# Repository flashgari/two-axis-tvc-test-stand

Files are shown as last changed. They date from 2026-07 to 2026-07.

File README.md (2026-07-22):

# Two-Axis Thrust Vector Control Test Stand

Hardware GNC portfolio project to design, build, and test a benchtop two-axis thrust-vector-control mechanism from scratch.

## Project Goal

Build a physical two-axis gimbal test stand that points a mock rocket engine/nozzle, measures actuator and attitude response, runs closed-loop control on embedded hardware, and produces real test data.

This project is intentionally hardware-first. The objective is to demonstrate the full engineering loop:

```text
requirements -> CAD -> fabrication -> electronics -> firmware -> calibration -> test data -> iteration
```

## Current Project Status

Prototype 1 is in the pre-hardware verification stage. The design package is no longer just a concept: requirements, actuator sizing, BOM, CAD baseline, split STL exports, firmware skeleton, serial logging, analysis scripts, and pre-hardware response predictions are already in the repo.

The next engineering question is:

```text
How closely does the real printed gimbal match the predicted pitch/yaw dynamic response?
```

That question is answered by comparing predicted and measured step-response metrics for each axis. A good first test is not judged by perfect motion. It is judged by whether the measured response exposes the dominant nonideality: actuator lag, servo deadband, gear backlash, printed-structure compliance, bearing friction, wire preload, center-of-mass bias, sensor filtering, or supply-voltage sag.

| Stage | Status | Evidence |
| --- | --- | --- |
| Requirements and safety scope | complete | [docs/week0_requirements.md](docs/week0_requirements.md), [docs/safety_plan.md](docs/safety_plan.md) |
| Hardware selection and purchase package | complete | [docs/final_purchase_package.md](docs/final_purchase_package.md) |
| CAD baseline and printable Rev A parts | complete | [cad/](cad/) |
| Firmware and telemetry skeleton | complete | [firmware/](firmware/) |
| Analysis and plotting pipeline | complete | [docs/test_and_analysis_workflow.md](docs/test_and_analysis_workflow.md) |
| Pre-hardware dynamic prediction | complete | [docs/pre_hardware_simulation.md](docs/pre_hardware_simulation.md) |
| Rev A design review | complete | [docs/rev_a_design_review_summary.md](docs/rev_a_design_review_summary.md) |
| Build readiness package | complete | [docs/build_readiness_checklist.md](docs/build_readiness_checklist.md) |
| Calibration and first-test worksheet | ready before hardware | [docs/hardware_calibration_worksheet.md](docs/hardware_calibration_worksheet.md) |
| Physical build and measured data | next | first servo-neutral and pitch/yaw step tests |

## Visual Evidence

### Two-Axis Gimbal Motion

Two-axis TVC gimbal motion

Open the browser-viewable animation here: [media/tvc_gimbal_animation.html](media/tvc_gimbal_animation.html).

This motion visual shows the key architecture before hardware arrives: the yaw frame rotates the full pitch/nozzle subsystem, while the pitch carrier rotates only the inner moving assembly. That is why yaw has larger rotational inertia and is expected to show slower response for the same servo torque limit. The purple thrust-vector direction is the mechanical control output that would create vehicle attitude-control torque in a flight vehicle.

### Rev A CAD Baseline

Prototype 1 CAD baseline

This CAD baseline shows the complete benchtop TVC plant: fixed base, outer yaw structure, inner pitch carrier, mock nozzle, servo envelopes, IMU placement, and hard-stop geometry. The important physics point is that this is not a decorative model. The moving mass distribution defines `I_axis`, the offset nozzle and wiring create disturbance moments, and the printed frame stiffness/damping will directly shape the measured step response.

### Predicted Pitch Step Response

Pre-hardware pitch step prediction

Pitch is predicted to respond faster because its moving inertia is mainly the nozzle carrier and inner pitch assembly. For a fixed useful servo torque, the angular acceleration follows `theta_ddot = tau_net / I_pitch`; lower inertia produces a faster rise time and shorter settling time. Any measured pitch response that is much slower than this prediction will point to underestimated friction, servo lag, printed-frame compliance, or supply-voltage droop.

### Predicted Yaw Step Response

Pre-hardware yaw step prediction

Yaw is predicted to be slower and more oscillatory because the yaw axis carries the pitch subsystem, servo mass, carrier, and nozzle. That increases `I_yaw` by roughly an order of magnitude relative to pitch in the current estimate. The physical expectation is therefore lower angular acceleration, longer settling time, and stronger sensitivity to backlash or frame compliance for the same actuator torque limit.

For a faster review path, open [FIGURE_INDEX.md](FIGURE_INDEX.md). For the Rev A engineering judgment, open [docs/rev_a_design_review_summary.md](docs/rev_a_design_review_summary.md).

## Why This Project

The previous 6-DOF rocket simulator demonstrated nonlinear flight dynamics, TVC allocation, LQR control, actuator dynamics, and robustness verification in software. This project turns that GNC stack into a physical test article.

The portfolio claim this project is designed to support:

> Personally designed, built, tested, and iterated a two-axis TVC hardware test stand with embedded sensing, actuation, closed-loop control, and measured performance data.

## Target Capabilities

| Capability | Target |
| --- | --- |
| Gimbal axes | 2-axis pitch/yaw |
| Angular range | At least `+/-10 deg` mechanical travel |
| Command tracking | Less than `1 deg` steady-state error after calibration |
| Step response | Settling time under `0.5 s` for small commands |
| Sensing | IMU attitude/rate measurement plus actuator command telemetry |
| Control | PID first, then optional model-based/LQR-inspired controller |
| Data logging | CSV logs for command, measured angle, IMU rate, error, and actuator output |
| Demonstration | Video of open-loop step response, closed-loop tracking, and disturbance rejection |

## Prototype 1 Hardware Baseline

Prototype 1 uses the lowest-cost architecture that still supports a real controls experiment. The intent is not to imitate a flight-qualified TVC actuator on the first pass. The intent is to build a benchtop plant with measurable inertia, friction, backlash, actuator saturation, sensor noise, and closed-loop tracking behavior.

| Subsystem | Selection |
| --- | --- |
| Microcontroller | Raspberry Pi Pico-class RP2040 board |
| IMU | BNO085-class fused IMU breakout |
| Actuators | Two Hitec HS-625MG metal-gear PWM servos |
| Power | External regulated `5-6 V` servo supply |
| Structure | 3D printed PLA+/PETG gimbal |
| Control | PID first, model-based comparison later |

Estimated Prototype 1 budget: about `$165-220` before tools, tax, and shipping.

This baseline was selected because it gets to hardware test data quickly while keeping the actuator assumptions defensible: the Pico is sufficient for a `50-100 Hz` embedded control loop, the BNO085 shortens attitude bring-up while still allowing sensor-performance discussion, Hitec HS-625MG servos provide traceable torque/speed/dimension data for CAD and test planning, and a printed structure allows rapid iteration after the first measured step-response and disturbance-rejection tests.

## CAD Baseline

The first CAD baseline is started in [cad/](cad/). It defines the coordinate convention, servo envelope assumptions, two-axis gimbal architecture, mock nozzle carrier, IMU placement, hard-stop philosophy, and Rev A design-review checklist.

Key CAD files:

- [cad/prototype1_parameters.md](cad/prototype1_parameters.md)
- [cad/prototype1_gimbal_baseline.scad](cad/prototype1_gimbal_baseline.scad)
- [cad/prototype1_cad_review.md](cad/prototype1_cad_review.md)
- [cad/rev_a_mass_inertia_estimate.md](cad/rev_a_mass_inertia_estimate.md)
- [cad/rev_a_print_and_assembly_plan.md](cad/rev_a_print_and_assembly_plan.md)
- [cad/rev_a_part_manifest.md](cad/rev_a_part_manifest.md)

Separated Rev A printable part files now live in [cad/parts/](cad/parts/), with rendered STL exports in [cad/exports/rev_a_parts/](cad/exports/rev_a_parts/). Each part is split out so its print orientation and structural role can be reviewed independently before physical fabrication.

Rev A keeps the CAD tied to the rotational plant:

```text
I_axis theta_ddot + c theta_dot + k theta = tau_servo + tau_disturbance
```

Current estimates are `73 g` moving mass and `3.0e-5 kg m^2` inertia for pitch, and `200 g` moving mass and `3.0e-4 kg m^2` inertia for yaw. Those values imply the first hardware tests should focus less on static torque and more on servo bandwidth, deadband, backlash, structural compliance, wire-induced bias, and repeatability.

## Firmware Baseline

The first Pico firmware skeleton is in [firmware/](firmware/), with the bring-up plan in [docs/firmware/firmware_bringup_plan.md](docs/firmware/firmware_bringup_plan.md).

The current firmware implements:

- servo neutral, sweep, and step command modes
- `+/-10 deg` firmware safety clamp
- angle-to-PWM mapping
- CSV telemetry over USB serial
- BNO085 detection/telemetry placeholder
- host-side tests for command limits and profiles

Firmware is treated as part of the physical plant, not just software. PWM commands are only actuator inputs; the measured IMU response will reveal servo deadband, backlash, finite speed, structural compliance, and cable-induced disturbance torques.

## Test And Analysis Pipeline

The verification workflow is documented in [docs/test_and_analysis_workflow.md](docs/test_and_analysis_workflow.md).

Current pipeline:

```text
pre-hardware model -> predicted response -> Pico serial CSV -> measured response -> model update
```

The repo includes a synthetic step-response example so the analysis stack can be tested before hardware arrives:

- `data/examples/synthetic_pitch_step.csv`
- `data/examples/synthetic_pitch_step.pitch.metrics.json`
- `plots/examples/synthetic_pitch_step_pitch_step_response.svg`

The analysis computes rise time, response delay, overshoot, settling time, steady-state error, peak tracking error, and hysteresis bias. These metrics are interpreted as evidence of actuator bandwidth, deadband, backlash, structural compliance, wire preload, and sensor filtering.

## Pre-Hardware Prediction Baseline

Before parts arrive, the project now includes a low-order dynamic response model in [docs/pre_hardware_simulation.md](docs/pre_hardware_simulation.md) and [scripts/simulate_pre_hardware_response.py](scripts/simulate_pre_hardware_response.py). This is not being used as a polished final truth model. It is a falsifiable engineering baseline that predicts how the printed gimbal should respond if the Rev A mass properties, useful servo torque, actuator lag, damping, stiffness, and disturbance torques are approximately correct.

The pre-hardware plant model is:

```text
I_axis theta_ddot + c theta_dot + k theta = tau_servo + tau_disturbance
delta_dot = (delta_cmd - delta) / tau_servo_lag
tau_servo = clamp(K_servo (delta - theta), -tau_limit, +tau_limit)
```

This connects CAD to controls: `I_axis` comes from the printed moving mass distribution, `c` represents friction and structural energy loss, `k` represents restoring stiffness and compliance, `tau_disturbance` represents center-of-mass offset and wire preload, and the servo model captures finite bandwidth and useful torque saturation. When real step-response logs are collected, differences between predicted and measured response become design evidence rather than guesswork.

The expected comparison logic is:

- slower measured rise time means the actuator/structure has lower effective bandwidth than assumed
- larger steady-state error means gravity bias, wire preload, servo deadband, or horn offset is under-modeled
- larger overshoot or ringing means damping is lower or structural compliance is higher than assumed
- approach-direction dependence means backlash and Coulomb friction need to be added to the plant model
- yaw underperformance relative to pitch is expected because yaw carries the pitch subsystem and therefore has much higher rotational inertia

## Build Transition

The project is ready to move from design artifacts to hardware purchase and first bench tests.

Build documents:

- [docs/final_purchase_package.md](docs/final_purchase_package.md)
- [docs/build_readiness_checklist.md](docs/build_readiness_checklist.md)
- [docs/rev_a_design_review_summary.md](docs/rev_a_design_review_summary.md)
- [docs/rev_a_inspection_checklist.md](docs/rev_a_inspection_checklist.md)
- [docs/first_hardware_test_procedure.md](docs/first_hardware_test_procedure.md)
- [docs/hardware_calibration_worksheet.md](docs/hardware_calibration_worksheet.md)
- [docs/first_test_report_template.md](docs/first_test_report_template.md)

Core purchase subtotal is currently about `$135.83` before tax and shipping. Full first-build estimate remains about `$165-220` after generic hardware, filament, and small tools/fixtures.

The first powered test must start with the servo horn removed. This prevents an unknown servo neutral from driving the mechanism into a hard stop.

## Week 1 Engineering Basis

The first sizing pass treats the gimbal/nozzle carrier as a rigid body with an offset center of mass. If the moving assembly has mass `m` and its center of mass is offset by `r` from the rotation axis, the static gravity moment is

```text
tau_gravity = m g r
```

Using `m = 0.20 kg` and `r = 0.04 m` gives `tau_gravity = 0.078 N m`, or about `0.80 kg-cm`. With a `3x` static margin, the first servo target is at least `2.4 kg-cm`, so Prototype 1 specifies `>= 5 kg-cm` metal-gear servos to leave margin for friction, cable drag, printed-frame compliance, and transient acceleration torque.

The more important controls question is not only whether the servo can hold the load. A TVC mechanism must track commanded angular deflection with finite bandwidth, limited authority, mechanical deadband, and imperfect sensing. That is why the first hardware tests will measure commanded angle, IMU-measured attitude/rate, settling time, overshoot, repeatability, and any neutral bias caused by wire loads or gimbal friction.

## System Architecture

```text
host computer
  -> sends test profile / receives serial logs

microcontroller
  -> reads IMU
  -> commands two actuators
  -> runs control loop
  -> streams telemetry

mechanical test stand
  -> fixed base
  -> two-axis gimbal
  -> mock engine/nozzle
  -> mechanical stops
```

## Repository Layout

```text
cad/        CAD notes, exported drawings, manufacturing notes
data/       raw test logs
docs/       requirements, safety, architecture, test plans, BOM trade studies
firmware/   embedded controller source and calibration sketches
media/      photos and demo video links
plots/      generated test plots
tests/      analysis scripts and hardware-in-the-loop test notes
```

## Week 0 Deliverables

- [x] Requirements document
- [x] System architecture
- [x] Safety plan
- [x] Preliminary hardware trade study
- [x] Test plan
- [x] Prototype 1 component architecture selected
- [x] Actuator sizing first pass
- [x] Wiring plan
- [x] CAD concept definition
- [x] Vendor shortlist before purchase
- [x] Final servo path selected before ordering
- [x] CAD baseline started
- [x] Rev A mass/inertia estimate
- [x] Rev A print and assembly plan
- [x] Rev A printable part split
- [x] Rev A individual STL exports
- [x] Pico firmware skeleton
- [x] Firmware bring-up plan
- [x] Data capture and analysis pipeline
- [x] Final purchase package
- [x] First hardware test procedure
- [x] Pre-hardware dynamic prediction model
- [x] Hardware calibration worksheet and log templates
- [x] Recruiter-facing figure index
- [x] Rev A design review summary
- [x] Build readiness checklist
- [x] Rev A inspection checklist
- [x] First hardware test report template
- [x] Gimbal motion animation
- [ ] Dimension-verified CAD after parts arrive
- [ ] Hardware servo-neutral test

## Near-Term Build Plan

1. Confirm HS-625MG servo dimensions, spline geometry, and horn package before Rev A CAD.
2. Design first-pass gimbal CAD with mechanical stops.
3. Build firmware skeleton for actuator commands and serial telemetry.
4. Calibrate IMU and actuator neutral positions.
5. Run open-loop step-response tests.
6. Implement closed-loop PID tracking.
7. Document failures, backlash, flex, saturation, noise, and design iterations.

## Safety Scope

This project starts with a mock engine/nozzle only. No live motors, pyrotechnics, high-pressure systems, or combustion hardware are part of the initial test stand.

The test article is a controls and mechanisms platform, not a propulsion test.

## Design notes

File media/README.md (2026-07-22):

# Media

Photos, screenshots, animations, and video links live here.

## Current Visuals

| File | Purpose |
| --- | --- |
| `tvc_gimbal_motion.svg` | GitHub-renderable animated schematic of the Rev A pitch/yaw gimbal motion. |
| `tvc_gimbal_animation.html` | Browser-viewable interactive motion animation with pitch/yaw angle readouts. |

The animation is a kinematic explanation, not a structural or controls simulation. It shows how the yaw frame carries the pitch/nozzle subsystem, while the pitch axis rotates the inner carrier. That architecture is physically important because it explains why the yaw-axis inertia is higher and why the pre-hardware model predicts slower yaw response for the same useful servo torque.

Portfolio media targets:

- CAD render
- gimbal motion animation
- assembled test stand photo
- wiring photo
- short open-loop test video
- short closed-loop tracking video
- short disturbance rejection video

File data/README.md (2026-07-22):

# Data

Raw test logs will live here.

Primary hardware step-response CSV format:

```text
time_ms, mode,
pitch_cmd_deg, meas_pitch_deg, pitch_pwm_us, gyro_pitch_dps,
yaw_cmd_deg, meas_yaw_deg, yaw_pwm_us, gyro_yaw_dps,
servo_supply_v, imu_status, test_id, notes
```

Keep raw logs unchanged. Processed metrics remain next to example datasets or next to the raw log, and generated plots should go in `plots/`.

Templates for first hardware testing live in `data/templates/`.

## Examples

Tracked example logs live in `data/examples/`. These are not hardware data; they are synthetic logs used to verify the analysis pipeline before the Pico is connected.

Raw hardware logs in `data/*.csv` are ignored by Git by default so accidental large or messy test files do not enter the repo.

## Physical Interpretation

The CSV format deliberately logs command, measured angle, PWM, gyro rate, and supply voltage together. Those channels separate physical failure modes:

- command changes without measured motion point to deadband, binding, wiring, or actuator power issues
- measured motion with supply-voltage sag points to current draw and power margin
- large gyro spikes with small angle motion point to IMU mounting vibration or sensor/filter artifacts
- final measured angle offset after a step points to gravity bias, wire preload, horn indexing, or servo deadband
- repeated tests with different final angles point to backlash or Coulomb friction rather than a purely linear plant

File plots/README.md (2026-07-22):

# Plots

Generated plots from hardware test data will live here.

Minimum plot set:

- command vs measured angle
- tracking error vs time
- actuator output vs time
- open-loop step response
- closed-loop step response
- disturbance rejection response

Example plots generated from synthetic logs live in `plots/examples/`.

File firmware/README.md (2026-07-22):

# Firmware

Prototype 1 firmware targets a Raspberry Pi Pico-class RP2040 board running MicroPython.

The first firmware milestone is safe open-loop bring-up:

```text
servo neutral -> limited sweep -> CSV telemetry -> IMU readout -> step response -> PID
```

## Current Firmware Files

| File | Purpose |
| --- | --- |
| `src/main.py` | Main Pico loop and selected test mode. |
| `src/config.py` | Physical constants, pins, loop rate, PWM limits, and command envelope. |
| `src/actuators.py` | Angle clamp, angle-to-PWM mapping, and servo command class. |
| `src/profiles.py` | Neutral, sweep, and step command profiles. |
| `src/imu_bno085.py` | BNO085 detection/telemetry placeholder. |
| `src/telemetry.py` | CSV header and row formatting. |
| `tests/` | Host-side checks for command limits and profiles. |

## Safety Defaults

The default mode in `src/main.py` is:

```python
MODE = "neutral"
```

Do not change to sweep or step modes until:

- servos have external `5 V` power
- servo supply ground and Pico ground are common
- the gimbal can move by hand through `+/-10 deg`
- hard stops are installed outside the firmware limit
- the mechanism is clamped or weighted on the bench

## Command Modes

Valid modes:

```text
neutral
sweep_pitch
sweep_yaw
step_pitch
step_yaw
```

The firmware clamps all angle commands to:

```text
+/-10 deg
```

The mechanical hard-stop target remains:

```text
about +/-15 deg
```

## Telemetry

The firmware streams CSV over USB serial:

```text
time_ms,mode,pitch_cmd_deg,yaw_cmd_deg,pitch_pwm_us,yaw_pwm_us,imu_present,quat_w,quat_x,quat_y,quat_z,gyro_x_dps,gyro_y_dps,gyro_z_dps
```

The BNO085 quaternion/rate fields are currently placeholders until the sensor driver is installed. The telemetry columns are defined now so future analysis scripts will not need to change format.

## Physical Interpretation

Servo PWM is an actuator input, not a guaranteed gimbal angle. The real plant is:

```text
I_axis theta_ddot + c theta_dot + k theta = tau_servo + tau_disturbance
```

The firmware controls the `tau_servo` side indirectly through PWM pulse width. The measured IMU response will show the real effects of servo deadband, gear backlash, finite speed, structural compliance, and cable-induced bias.

That is why the first firmware milestone is open-loop telemetry, not immediate closed-loop PID. Before tuning a controller, the actuator and mechanism must be characterized.

## Host-Side Test

From the repo root:

```bash
python3 -m unittest discover firmware/tests
```

These tests verify that the angle-to-PWM mapping clamps commands before they can exceed the Rev A firmware envelope.

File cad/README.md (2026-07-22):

# CAD Baseline

CAD files, exported drawings, and manufacturing notes live here.

## Prototype 1 Baseline

Prototype 1 uses two Hitec HS-625MG metal-gear servos and a 3D printed nested gimbal layout.

Prototype 1 CAD baseline

| File | Purpose |
| --- | --- |
| `prototype1_parameters.md` | Traceable dimensional assumptions, servo specs, axis convention, and quantities to verify. |
| `prototype1_gimbal_baseline.scad` | Parametric OpenSCAD first-pass model. |
| `prototype1_cad_review.md` | CAD design intent, physical rationale, review checklist, and expected Rev A failure modes. |
| `rev_a_mass_inertia_estimate.md` | First-pass moving mass, center-of-mass, gravity moment, and inertia estimates. |
| `rev_a_print_and_assembly_plan.md` | Printable part breakdown, assembly order, inspection checks, and physics rationale. |
| `rev_a_part_manifest.md` | Separated printable part list with orientation, physics rationale, and fit-check sequence. |
| `exports/prototype1_cad_baseline.svg` | Static layout preview for GitHub/recruiter review. |
| `exports/prototype1_gimbal_baseline.stl` | OpenSCAD-rendered review STL of the combined layout assembly. |

## Export Status

The combined layout model has been rendered in OpenSCAD and exported as `exports/prototype1_gimbal_baseline.stl`.

This STL is **review evidence**, not a final print package. It proves that the parametric CAD baseline renders as a valid 3D object, but the assembly still needs to be split into manufacturing parts before printing:

- base plate
- yaw servo mount
- outer yaw frame
- pitch servo mount
- inner pitch/nozzle carrier
- mock nozzle
- hard-stop blocks
- wire strain-relief clips

The physical reason for separating the parts is that each component has a different print orientation, stiffness requirement, and failure mode. For example, servo mounts need strong screw-hole walls, the pitch carrier needs low moving inertia, and strain-relief clips need to control wire-induced torque without adding unnecessary mass to the moving body.

## Rev A Printable Parts

Individual Rev A part files are in [parts/](parts/):

| Part | OpenSCAD file |
| --- | --- |
| base plate | `parts/base_plate.scad` |
| yaw servo mount | `parts/yaw_servo_mount.scad` |
| outer yaw frame | `parts/outer_yaw_frame.scad` |
| pitch servo mount | `parts/pitch_servo_mount.scad` |
| inner pitch/nozzle carrier | `parts/inner_pitch_carrier.scad` |
| mock nozzle | `parts/mock_nozzle.scad` |
| hard-stop block | `parts/hard_stop_block.scad` |
| wire strain-relief clip | `parts/wire_strain_relief_clip.scad` |

Individual Rev A STL exports are in [exports/rev_a_parts/](exports/rev_a_parts/). The export log is [exports/rev_a_parts/export_log.md](exports/rev_a_parts/export_log.md).

To export one part, open its `.scad` file in OpenSCAD, press `F6`, then use `File -> Export -> Export as STL`.

The command-line equivalent is:

```text
/Applications/OpenSCAD-2021.01.app/Contents/MacOS/OpenSCAD \
  -o cad/exports/rev_a_parts/base_plate.stl \
  cad/parts/base_plate.scad
```

First CAD revision should include:

- fixed base
- outer gimbal frame
- inner gimbal frame
- mock nozzle
- actuator mounts
- linkage/horn geometry
- mechanical stops
- IMU mounting surface
- wire routing/strain relief

Design priorities:

1. Easy to print and assemble.
2. Easy to modify after first test.
3. Stiff enough for repeatable measurements.
4. Clear axis definitions for pitch and yaw.

## CAD Philosophy

The first model is deliberately parametric because the hardware will be measured after arrival. Servo body dimensions, horn thickness, spline fit, IMU board dimensions, moving mass, and center of mass should be updated before final printing.

The CAD is evaluated by how well it supports test data, not just how clean it looks. The stand should make it possible to identify actuator bandwidth, backlash, frame compliance, cable-induced bias, and IMU measurement issues from controlled experiments.

## Rev A Physical Model

The CAD package keeps the mechanical design tied to the rotational plant:

```text
I_axis theta_ddot + c theta_dot + k theta = tau_servo + tau_disturbance
```

The Rev A mass estimate predicts:

| Axis | Moving mass estimate | Inertia estimate | Gravity moment estimate |
| --- | ---: | ---: | ---: |
| pitch | `73 g` | `3.0e-5 kg m^2` | `0.018 N m` |
| yaw | `200 g` | `3.0e-4 kg m^2` | `0.039 N m` |

These estimates suggest the first prototype should be limited more by servo speed, deadband, backlash, structural compliance, and wiring disturbances than by static torque. The hardware tests should therefore emphasize step response, hysteresis, steady-state bias, and repeatability.

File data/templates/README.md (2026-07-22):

# Data Templates

These CSV templates define the expected structure for first hardware logs.

| File | Purpose |
| --- | --- |
| `calibration_record_template.csv` | Records neutral PWM, mechanical zero, range, voltage, IMU bias, and hysteresis observations. |
| `hardware_step_log_template.csv` | Defines the telemetry columns required by the step-response analysis pipeline. |

The most important fields for analysis are:

```text
time_ms
pitch_cmd_deg / yaw_cmd_deg
meas_pitch_deg / meas_yaw_deg
pitch_pwm_us / yaw_pwm_us
gyro_pitch_dps / gyro_yaw_dps
```

The extra fields, such as `servo_supply_v`, `imu_status`, `test_id`, and `notes`, make the data useful for engineering diagnosis. For example, a slow response with a simultaneous supply-voltage drop points to actuator power margin, while a clean voltage trace with high hysteresis points more toward backlash, friction, or spline looseness.

The first measured log should be analyzed with:

```bash
python3 scripts/analyze_step_response.py data/<log>.csv --axis pitch
python3 scripts/plot_step_response.py data/<log>.csv --axis pitch
```

Then compare the result against the pre-hardware prediction files in `data/examples/`.

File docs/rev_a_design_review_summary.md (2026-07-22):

# Rev A Design Review Summary

## Review Objective

Assess whether Prototype 1 Rev A is ready to move from design artifacts to physical fabrication, calibration, and first measured step-response testing.

Rev A is intentionally a benchtop controls/mechanisms article, not a flight-like actuator. Its purpose is to generate measured plant behavior that can be compared against a pre-hardware dynamic prediction.

## Design Status

| Area | Status | Evidence |
| --- | --- | --- |
| Requirements | ready | two-axis range, command tracking, data logging, safety scope |
| Actuator selection | ready | Hitec HS-625MG selected for traceable dimensions/torque/speed |
| Electronics | ready | Pico-class controller, BNO085-class IMU, external servo supply |
| CAD baseline | ready for first print | parametric OpenSCAD assembly plus split printable STL exports |
| Firmware | ready for bring-up | neutral, sweep, step profile, PWM clamp, telemetry skeleton |
| Analysis | ready | CSV logging, metrics extraction, plotting, synthetic and pre-hardware examples |
| Test planning | ready | neutral procedure, calibration worksheet, log templates |
| Hardware data | pending | requires purchased parts and printed Rev A hardware |

## Key Physical Model

The gimbal is treated as a low-order rotational plant:

```text
I_axis theta_ddot + c theta_dot + k theta = tau_servo + tau_disturbance
delta_dot = (delta_cmd - delta) / tau_servo_lag
tau_servo = clamp(K_servo (delta - theta), -tau_limit, +tau_limit)
```

This model is deliberately simple enough to be identifiable from first hardware logs. Each term maps to a physical feature:

| Term | Physical source in Rev A |
| --- | --- |
| `I_axis` | printed moving mass, servo placement, nozzle carrier, pitch assembly carried by yaw |
| `c theta_dot` | servo geartrain friction, bearing losses, plastic flex damping, cable rubbing |
| `k theta` | frame compliance, wire preload stiffness, gravity-restoring/anti-restoring geometry |
| `tau_disturbance` | center-of-mass offset, horn indexing error, cable routing bias |
| `tau_servo_lag` | internal servo controller bandwidth, PWM update rate, mechanical response lag |
| `tau_limit` | useful dynamic torque, intentionally below datasheet stall torque |

## Design Strengths

1. **Traceable engineering chain:** Requirements, hardware selection, CAD, firmware, data logging, analysis, and test planning are connected instead of existing as isolated files.

2. **Falsifiable prediction before hardware:** The pre-hardware response model publishes assumptions before test data exists. This makes later deviations meaningful evidence rather than post-hoc explanation.

3. **Axis-specific physics:** Pitch and yaw are not assumed to behave identically. Yaw carries the pitch subsystem, so larger yaw inertia should produce slower response and potentially larger sensitivity to compliance/backlash.

4. **Safety-first bring-up:** The first powered procedure starts with servo horns removed, then progresses through neutral verification, limited sweep, and measured step tests.

5. **Data interpretation plan:** Step-response metrics are tied to physical causes such as actuator lag, friction, backlash, compliance, wire preload, sensor filtering, and voltage sag.

## Remaining Rev A Risks

| Risk | Why it matters physically | First test that exposes it |
| --- | --- | --- |
| Servo horn spline mismatch | creates neutral offset and trim moment | servo-neutral calibration |
| Printed frame compliance | reduces effective stiffness and can add phase lag/overshoot | pitch/yaw step response |
| Gear backlash or horn slop | creates approach-direction hysteresis not captured by linear model | `-5 -> +5 -> -5 deg` hysteresis test |
| Wire preload | adds a constant or weakly elastic disturbance torque | neutral repeatability and steady-state error |
| Servo supply droop | reduces available torque and speed during motion | step test with voltage logging |
| IMU sign/filter issue | can destabilize feedback or corrupt derivative estimate | hand-deflection sign and rate check |
| Bearing/bushing friction | consumes servo torque and slows rise time | measured rise time vs prediction |

## First Hardware Validation Plan

The first hardware campaign should proceed in this order:

1. Servo-neutral test with horns removed.
2. Horn indexing and mechanical-zero calibration.
3. IMU sign, zero, and rate verification.
4. `+/-2 deg` low-risk pitch and yaw step tests.
5. `+/-5 deg` pitch and yaw step tests for comparison with pre-hardware prediction.
6. Hysteresis tests using negative-to-positive and positive-to-negative approach paths.
7. Update model parameters from measured rise time, overshoot, settling time, steady-state error, and hysteresis bias.

## What Rev B Depends On

Rev B should not be designed by preference. It should be driven by measured failure mode:

| Measured result | Rev B design response |
| --- | --- |
| rise time much slower than predicted | reduce moving inertia, increase servo torque margin, reduce friction, improve supply stiffness |
| large steady-state error | rebalance moving assembly, reroute wires, refine horn indexing, add trim calibration |
| high overshoot/ringing | stiffen frame, shorten load paths, improve bearing support, reduce controller aggressiveness |
| large hysteresis bias | improve horn coupling, reduce slop, add better bearings/bushings, redesign joints |
| yaw much worse than predicted | reduce mass carried by yaw, move pitch servo closer to yaw axis, increase yaw actuator authority |
| noisy attitude/rate telemetry | improve IMU mounting, isolate vibration, check power noise, adjust filtering |

## Review Conclusion

Rev A is ready to proceed to purchase, printing, assembly, and first powered calibration. The design is not claimed to be final. It is a controlled first article intended to generate measured plant data.

The project will be strongest when the first hardware results are presented as:

```text
prediction -> measured response -> physical discrepancy -> design update
```

That loop demonstrates personally designed, built, and tested aerospace hardware with a controls-oriented engineering interpretation.

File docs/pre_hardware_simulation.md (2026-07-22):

# Pre-Hardware Gimbal Simulation

## Objective

Create a prediction baseline before hardware arrives. The goal is not to claim the model is exact. The goal is to state the assumptions clearly, predict first-order behavior, then compare the prediction against measured data after the first servo tests.

## Model

Each gimbal axis is modeled as:

```text
I_axis theta_ddot + c theta_dot + k theta = tau_servo + tau_disturbance
```

The servo is modeled as a first-order actuator lag:

```text
delta_dot = (delta_cmd - delta) / tau_servo_lag
```

and the torque command is saturated:

```text
tau_servo = clamp(K_servo (delta - theta), -tau_limit, +tau_limit)
```

This captures the key physical effects expected in Rev A:

- moving inertia from the printed gimbal/nozzle
- damping from bearings, geartrain friction, and structural losses
- stiffness from gravity coupling, printed-frame compliance, and wire preload
- actuator lag from the HS-625MG internal servo loop
- saturation from finite useful torque
- disturbance torque from center-of-mass offset and cable loads

## Assumptions

The simulation uses the current Rev A mass/inertia estimates:

| Axis | Inertia | Gravity/disturbance torque | Interpretation |
| --- | ---: | ---: | --- |
| pitch | `3.0e-5 kg m^2` | `0.018 N m` | lighter moving carrier and nozzle |
| yaw | `3.0e-4 kg m^2` | `0.039 N m` | larger inertia because yaw carries the pitch subsystem |

The useful servo torque is capped at `0.13 N m`, about `20%` of the HS-625MG stall torque at `6 V`. This avoids pretending stall torque is available for clean dynamic control.

## Generated Files

Run:

```bash
python3 scripts/simulate_pre_hardware_response.py
python3 scripts/analyze_step_response.py data/examples/prehardware_pitch_step_prediction.csv --axis pitch
python3 scripts/analyze_step_response.py data/examples/prehardware_yaw_step_prediction.csv --axis yaw
python3 scripts/plot_step_response.py data/examples/prehardware_pitch_step_prediction.csv --axis pitch
python3 scripts/plot_step_response.py data/examples/prehardware_yaw_step_prediction.csv --axis yaw
```

Outputs:

```text
data/examples/prehardware_model_parameters.json
data/examples/prehardware_pitch_step_prediction.csv
data/examples/prehardware_yaw_step_prediction.csv
data/examples/prehardware_pitch_step_prediction.pitch.metrics.json
data/examples/prehardware_yaw_step_prediction.yaw.metrics.json
plots/examples/prehardware_pitch_step_prediction_pitch_step_response.svg
plots/examples/prehardware_yaw_step_prediction_yaw_step_response.svg
```

## Upper-Division Physical Interpretation

The pre-hardware model is valuable because it creates a falsifiable expectation:

- If measured rise time is much slower than predicted, actuator lag, friction, or binding is larger than assumed.
- If measured steady-state error is larger than predicted, center-of-mass offset, wire preload, or servo deadband is likely under-modeled.
- If measured overshoot is larger than predicted, damping is lower or structural compliance is higher than assumed.
- If measured response depends on approach direction, backlash/hysteresis is missing from the current linear model.
- If yaw performs much worse than pitch, the larger yaw inertia and pitch-servo-on-yaw mass are probably dominating.

This makes the first hardware data more meaningful. The plot is not just "what happened"; it becomes a comparison between predicted plant behavior and measured plant behavior.

## How This Supports The Portfolio

This is the correct engineering sequence:

```text
CAD mass estimate -> pre-hardware dynamic model -> predicted plots -> physical test -> model update
```

That sequence shows aerospace reasoning because it connects geometry, mass properties, actuator limits, differential equations, measured response, and design iteration.

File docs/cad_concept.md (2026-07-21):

# CAD Concept

## Prototype 1 Mechanical Concept

The first CAD model will be a compact two-axis gimbal for a mock nozzle. The mechanism is a benchtop controls test article, so the design prioritizes access, stiffness, and iteration speed over flight-like packaging.

The CAD model is not just a visual deliverable. It defines the plant that the controller will later regulate: axis alignment, center-of-mass offset, moving inertia, friction sources, cable routing, hard-stop geometry, and sensor placement. Small mechanical choices directly affect the control data, so every CAD revision should be tied to a physical hypothesis that can be tested.

## Coordinate Convention

```text
base frame:
  +z = up
  +x = pitch direction reference
  +y = yaw direction reference

gimbal axes:
  outer frame = yaw axis
  inner frame = pitch axis
```

The exact naming can be adjusted during CAD, but the axis convention must be documented so test data matches the firmware sign convention.

## Major Parts

| Part | Function |
| --- | --- |
| Base plate | Holds the full stand rigidly on the bench |
| Outer gimbal frame | Carries one rotational axis |
| Inner gimbal/nozzle carrier | Carries the mock nozzle and IMU |
| Mock nozzle | Visual engine/nozzle surrogate with known approximate mass |
| Servo mounts | Hold pitch/yaw servos with adjustable alignment |
| Mechanical stops | Prevent overtravel beyond safe range |
| IMU platform | Places sensor near moving body with known orientation |
| Wire relief | Prevents cable drag from becoming a disturbance torque |

## Design Targets

| Feature | Target |
| --- | --- |
| Angular range | At least `+/-10 deg` both axes |
| Hard stops | `+/-15 deg` approximate mechanical limit |
| Fasteners | Common M3 or equivalent |
| Assembly | Removable actuator mounts and nozzle carrier |
| Print strategy | Avoid supports where possible |
| Sensor mount | Flat surface with repeatable orientation |

## Actuator Geometry

Prototype 1 can use one of two servo layouts:

### Direct Horn Layout

Servo horn directly rotates the gimbal axis.

Strength:

- simple
- fewer parts
- easy firmware mapping

Risk:

- axis alignment must be good
- servo backlash directly appears as gimbal backlash

### Linkage Layout

Servo horn drives the gimbal through a pushrod/link.

Strength:

- easier to package
- mechanical advantage can be tuned

Risk:

- linkage slop
- nonlinear angle mapping
- harder calibration

Recommended Prototype 1 direction: direct horn if mechanically feasible; linkage only if packaging forces it.

The direct-drive option is preferred for the first build because it keeps the kinematic mapping between servo angle and gimbal angle close to linear. That makes calibration and control interpretation cleaner. A linkage can be useful later, but it introduces angle-dependent mechanical advantage and additional compliance, so any controller comparison would have to account for that nonlinear input mapping.

## IMU Placement

The IMU should be mounted on the moving inner gimbal/nozzle carrier, not the fixed base. The sensor axes should be aligned with the documented gimbal axes as closely as possible.

Important:

- Record sensor orientation in CAD.
- Add a visible arrow or label for sensor `+x/+y`.
- Keep the IMU wire flexible and strain-relieved.

Mounting the IMU on the moving carrier means the measured attitude corresponds to the controlled output, not the fixed base. However, this also exposes the sensor to local vibration and cable-induced loads. The CAD should therefore place the IMU on a stiff region of the carrier and route wires so they do not add a hidden restoring torque or bias the neutral angle.

## Mechanical Stops

Mechanical stops should limit travel before the servo or linkage binds.

Initial target:

```text
firmware command limit: +/-10 deg
mechanical hard stop: about +/-15 deg
```

The gap between firmware limit and hard stop gives protection against calibration error.

## CAD Deliverables

First CAD milestone should produce:

- screenshot/render of full assembly
- exploded or annotated view
- axis convention figure
- approximate moving mass estimate
- hardware list for fasteners/bearings
- print orientation notes

## Known First-Prototype Risks

- printed-frame flex changes measured response
- servo backlash dominates tracking error
- wire drag biases neutral position
- IMU mount vibration contaminates rate measurements
- direct-drive geometry may not package cleanly

The first CAD revision should make these risks easy to inspect and modify.

These risks are expected, not embarrassing. A strong hardware portfolio project shows that the first design was instrumented well enough to identify the failure mode. For example, if measured attitude lags command even at low frequency, the likely cause may be servo bandwidth or sensor filtering. If the steady-state neutral angle changes after moving in opposite directions, backlash or cable preload is more likely. The CAD should make those effects observable instead of hiding them inside inaccessible geometry.

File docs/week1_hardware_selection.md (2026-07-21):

# Week 1 Hardware Selection

## Prototype 1 Decision

Prototype 1 will use the low-cost, fast-bring-up architecture:

| Subsystem | Selected baseline | Reason |
| --- | --- | --- |
| Microcontroller | Raspberry Pi Pico-class RP2040 board | Low cost, deterministic enough for servo/IMU control, strong documentation |
| IMU | BNO085-class fused IMU breakout | Fast attitude bring-up; useful for early closed-loop tests |
| Actuators | Two metal-gear PWM servos | Simple control interface, easy mechanical integration, inexpensive |
| Power | External regulated `5-6 V` servo supply | Prevents servo current spikes from browning out the microcontroller |
| Structure | 3D printed PLA+/PETG gimbal | Fast iteration and easy redesign after first tests |
| Control approach | PID first | Establishes measured hardware performance before model-based control |

## Why Option A

The first prototype needs to generate real hardware data quickly. A more advanced board/sensor/actuator stack can be justified later, but the first engineering win is a working physical mechanism with measured response.

Option A is also cheaper. The Raspberry Pi Pico-class board is roughly an order of magnitude cheaper than a Teensy-class board, while still providing enough PWM, I2C, timing, and serial telemetry for the first test stand.

The lower-cost architecture does not remove the aerospace content of the project. It changes the first research question. Instead of asking whether an expensive actuator can be made to work, Prototype 1 asks whether a real two-axis plant can be characterized well enough to close the loop despite actuator nonidealities. That is a controls-relevant hardware problem: the controller must operate with finite servo bandwidth, backlash, sensor latency, structural compliance, and command saturation.

For a TVC stand, those effects are not side details. They determine the mapping from commanded nozzle deflection to measured attitude response. The same control law that looks stable in simulation can become sluggish, biased, or oscillatory if the actuator has deadband, if the IMU is mounted on a vibrating printed carrier, or if cable loads create an unmodeled restoring/disturbance moment. Prototype 1 is selected specifically because these physical effects can be measured, plotted, and used to justify later design changes.

## Estimated Prototype 1 Cost

Prices vary by vendor and availability. This estimate is for planning only.

| Item | Qty | Planning cost |
| --- | ---: | ---: |
| Raspberry Pi Pico-class board | 1 | `$4-8` |
| BNO085-class IMU breakout | 1 | `$25` |
| Metal-gear servos | 2 | `$20-40` total |
| Servo power supply/regulator | 1 | `$10-20` |
| Breadboard/wires/connectors | 1 set | `$10-20` |
| Bearings/shafts/fasteners | 1 set | `$10-25` |
| 3D print material | 1 set | `$5-15` |
| **Expected total** |  | **about `$85-150`** |

## Hardware Baseline

### Microcontroller

The RP2040/Pico baseline is sufficient for:

- two PWM servo outputs
- I2C IMU communication
- `50-100 Hz` control loop
- USB serial telemetry
- command profile generation

The main limitation is that it is not as powerful as a Teensy 4.1. That is acceptable for Prototype 1 because the controller will start as PID and the test stand is not flight hardware.

The expected loop rate of `50-100 Hz` is adequate for hobby-servo dynamics because the actuator mechanical bandwidth is likely lower than the processor limit. In other words, the first bottleneck is expected to be the electromechanical plant, not floating-point throughput. That makes the Pico a rational first-build choice.

### IMU

The BNO085 baseline provides fused attitude output, which reduces bring-up time. The project should still log raw gyro/accel channels if available, because the engineering story should not be "trust the black box." The BNO085 is used to accelerate the first hardware demonstration, not to avoid sensor reasoning.

This is a deliberate sensor-fusion trade. A fused IMU output reduces the initial burden of writing a full attitude estimator, but it introduces estimator latency, internal filtering, and algorithm behavior that must be acknowledged. The test data should therefore compare command, measured attitude, and measured angular rate so the writeup can separate plant dynamics from sensor/filter dynamics.

### Actuators

Prototype 1 uses hobby-class metal-gear PWM servos. Their known weaknesses are part of the test objective:

- backlash
- deadband
- finite bandwidth
- gear compliance
- current spikes
- no true torque telemetry

The project should measure these limitations instead of pretending they do not exist.

Servo limitations are especially relevant for thrust vector control because actuator lag creates phase delay in the feedback loop. Too much delay reduces phase margin and can turn an otherwise stable controller into an oscillatory one. Backlash and deadband also create a region where small control efforts do not immediately produce nozzle motion, which is exactly the kind of nonlinearity that should appear in step-response and small-command tracking tests.

### Structure

The first gimbal should be 3D printed and deliberately easy to modify. The design should include:

- outer frame
- inner gimbal/nozzle carrier
- actuator mounts
- mechanical hard stops
- IMU mount
- wire strain relief
- accessible fasteners

## Prototype 1 Acceptance Criteria

Prototype 1 is successful when it can:

1. Move both axes through at least `+/-10 deg`.
2. Read and log IMU attitude/rate.
3. Record open-loop step response.
4. Track a small single-axis command in closed loop.
5. Produce commanded-vs-measured plots.
6. Document at least one physical limitation and design iteration.

## Week 1 Deliverables

- [x] Hardware baseline selected
- [x] Cost estimate
- [x] Actuator sizing first pass
- [x] CAD concept definition
- [x] Wiring plan
- [x] Purchase checklist
- [ ] Final vendor links before purchase
- [ ] First CAD model

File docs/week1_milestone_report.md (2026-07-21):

# Week 1 Milestone Report

## Objective

Select the Prototype 1 hardware architecture and define the first mechanical/electrical design baseline before purchasing parts or starting CAD.

## Decision

Prototype 1 will use the low-cost Option A architecture:

| Subsystem | Selection |
| --- | --- |
| Microcontroller | Raspberry Pi Pico-class RP2040 board |
| IMU | BNO085-class fused IMU breakout |
| Actuators | Two metal-gear PWM servos |
| Power | External regulated `5-6 V` servo supply |
| Structure | 3D printed PLA+/PETG gimbal |
| Control | PID first, model-based comparison later |

## Why This Is The Right First Prototype

The project goal is to demonstrate a complete hardware design-build-test loop. Prototype 1 should therefore minimize bring-up risk and cost while still producing meaningful engineering data.

The Pico-class microcontroller is inexpensive and sufficient for:

- two PWM actuator outputs
- I2C IMU communication
- `50-100 Hz` control loop
- USB serial CSV telemetry

The BNO085-class IMU reduces early attitude-estimation workload so the first prototype can reach closed-loop hardware testing faster. Raw gyro/accel channels should still be logged where available to preserve sensor-analysis depth.

Metal-gear PWM servos are not perfect actuators. They have backlash, finite bandwidth, deadband, and current spikes. That is acceptable because the first hardware milestone is to measure and document those limitations, not hide them.

The selected architecture is cheap, but it still captures the main controls physics of a TVC mechanism. The gimbal is a rotational plant with inertia, damping, stiffness/compliance, saturation, and disturbance torques. The embedded controller will command nozzle angle, the servos will impose actuator dynamics and deadband, and the IMU will measure the resulting attitude/rate response with its own latency and filtering. Those are exactly the effects that determine whether a thrust-vectoring system has enough bandwidth and phase margin to reject disturbances.

This first prototype is therefore not trying to prove that hobby hardware is flight hardware. It is trying to prove that the mechanism can be designed, built, instrumented, tested, and improved using measured data. That is the portfolio value.

## Cost Estimate

Expected Prototype 1 cost:

```text
about $85-150 before tools
```

The exact total depends mostly on servo selection, fasteners/bearings, and whether headers/cables/power hardware are already available.

## Actuator Sizing Result

Using a conservative static estimate:

```text
m = 0.20 kg
r = 0.04 m
tau_gravity = m g r = 0.078 N m ~= 0.80 kg-cm
```

With a `3x` margin:

```text
tau_servo,target >= 2.4 kg-cm
```

Prototype 1 should select servos with at least `5 kg-cm` stall torque to leave margin for friction, wiring drag, printed-frame flex, and dynamic motion.

This sizing result should be read as a lower-bound screen, not a final actuator certification. Static stall torque only says the servo should hold the moving mass against gravity. Closed-loop TVC performance also depends on dynamic response:

```text
I_axis theta_ddot + c theta_dot + k theta ~= tau_servo + tau_disturbance
```

where `I_axis` is the moving assembly inertia, `c` represents effective damping, `k` represents structural/cable stiffness or gravity coupling, and `tau_disturbance` includes wire drag, friction, and off-axis loads. The first step-response tests will use measured rise time, overshoot, settling time, and steady-state bias to identify whether the limiting factor is torque, bandwidth, backlash, compliance, or sensor filtering.

## CAD Baseline

The first CAD concept will use:

- fixed base
- outer gimbal frame
- inner nozzle carrier
- mock nozzle
- direct servo drive if packaging allows
- mechanical hard stops around `+/-15 deg`
- firmware command limits around `+/-10 deg`
- IMU mounted on the moving nozzle carrier
- visible sensor-axis markings
- wire strain relief

## Wiring Baseline

The electrical architecture is:

```text
USB laptop -> Pico-class microcontroller
Pico I2C -> BNO085 IMU
Pico PWM -> pitch/yaw servos
external 5-6 V supply -> servo power
servo supply ground == microcontroller ground
```

Servos will not be powered from the microcontroller USB rail.

The separate servo supply is an engineering requirement, not just a wiring preference. Servo current spikes can pull down the logic rail, reset the microcontroller, corrupt telemetry, or create IMU noise during motion. A common ground is still required so the PWM signal has a valid voltage reference at the servo input.

## Next Work

1. Choose exact vendor links and servo model.
2. Confirm servo dimensions and horn geometry.
3. Create first CAD assembly.
4. Create firmware skeleton for PWM neutral, IMU readout, and CSV telemetry.
5. Run actuator neutral/range tests once hardware arrives.

## Portfolio Relevance

This milestone turns the project from an idea into an engineering baseline. It records design choices, cost reasoning, actuator sizing, wiring constraints, and CAD requirements before hardware is purchased.

The key result from Week 1 is that the first build has a defensible requirements chain: target gimbal motion leads to actuator torque screening, actuator choice leads to power and wiring constraints, CAD geometry determines inertia and disturbance moments, and sensor placement determines what state is actually measured for feedback. That chain is what makes the project read like an aerospace controls build instead of a parts assembly.

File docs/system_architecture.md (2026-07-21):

# System Architecture

## High-Level Architecture

```text
USB host laptop
  | serial commands / telemetry
  v
microcontroller
  | PWM actuator commands
  | I2C/SPI IMU data
  v
two-axis gimbal test stand
  | measured angular response
  v
CSV logs and plots
```

## Subsystems

### Mechanical

Purpose: provide a rigid, adjustable two-axis gimbal for a mock nozzle.

Initial concept:

- fixed base plate
- outer pitch/yaw frame
- inner gimbal frame
- mock engine/nozzle cylinder
- two actuator linkages or direct servo horns
- mechanical hard stops
- IMU mount close to moving body

Key mechanical risks:

- backlash in servo gears/linkages
- flex in printed brackets
- axis misalignment
- wire drag applying unwanted torque
- insufficient base stiffness

### Electronics

Purpose: command actuators, read sensor data, and stream telemetry.

Initial architecture:

- microcontroller with hardware PWM and fast serial logging
- 6-axis or 9-axis IMU mounted to gimbal body
- separate regulated actuator power
- common ground between logic and actuator supply
- emergency unplug or power switch

Key electronics risks:

- servo current causing microcontroller brownout
- IMU vibration/noise
- ground noise coupling into sensor readings
- unstable power from USB-only supply

### Firmware

Purpose: run deterministic control and log test data.

Firmware modules:

- actuator command interface
- IMU read/calibration
- command profile generator
- PID controller
- safety limits
- serial telemetry logger

Telemetry columns:

```text
time_s, cmd_pitch_deg, cmd_yaw_deg,
meas_pitch_deg, meas_yaw_deg,
gyro_x_radps, gyro_y_radps, gyro_z_radps,
err_pitch_deg, err_yaw_deg,
actuator_pitch_us, actuator_yaw_us,
mode
```

### Test And Analysis

Purpose: convert real hardware data into engineering evidence.

Initial plots:

- commanded vs measured pitch
- commanded vs measured yaw
- tracking error vs time
- actuator output vs time
- step response metrics
- disturbance rejection response

## Control Development Sequence

1. Actuator neutral and range calibration.
2. Open-loop command sweep.
3. Single-axis step response.
4. Single-axis PID tracking.
5. Two-axis coupled tracking.
6. Disturbance rejection.
7. Optional model-based controller comparison.

## Physical Interpretation

The test stand is a hardware analog of the simulator TVC loop:

```text
controller command -> actuator dynamics -> achieved gimbal angle -> measured attitude/rate
```

The main engineering question is not whether a servo can move. The question is whether the achieved motion follows the command with enough bandwidth, low enough steady-state error, and small enough backlash/noise to support closed-loop attitude control.

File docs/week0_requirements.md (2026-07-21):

# Week 0 Requirements

## Mission Statement

Design, build, and test a benchtop two-axis thrust-vector-control test stand that demonstrates embedded control, actuator characterization, sensor integration, and measured closed-loop performance.

## Primary Requirement

The system shall command and measure two-axis gimbal motion for a mock rocket nozzle and demonstrate closed-loop tracking and disturbance rejection using real hardware data.

## Functional Requirements

| ID | Requirement | Verification |
| --- | --- | --- |
| FR-1 | The mechanism shall provide two rotational degrees of freedom representing pitch and yaw TVC. | CAD inspection and manual range test |
| FR-2 | The gimbal shall provide at least `+/-10 deg` mechanical travel on both axes. | Protractor/IMU measurement |
| FR-3 | The firmware shall command both actuators independently. | Serial command test |
| FR-4 | The firmware shall log time, command angle, measured angle, angular rate, tracking error, and actuator output. | CSV log inspection |
| FR-5 | The system shall run a repeatable step-response test profile. | Test script and plotted response |
| FR-6 | The system shall run closed-loop tracking on at least one axis, then both axes. | Closed-loop test data |
| FR-7 | The system shall include mechanical stops that prevent actuator overtravel. | Physical inspection |
| FR-8 | The system shall use a mock engine/nozzle for initial testing. | Physical inspection |

## Performance Targets

| Metric | Target | Rationale |
| --- | ---: | --- |
| Small-step settling time | `< 0.5 s` | Demonstrates usable actuator bandwidth |
| Steady-state command error | `< 1 deg` | Shows calibration and control accuracy |
| Overshoot | `< 20%` for first controlled tests | Keeps tuning conservative |
| Sample/log rate | `>= 50 Hz` | Captures servo-scale dynamics |
| Mechanical travel | `+/-10 deg` minimum | Representative TVC envelope |

## Engineering Requirements

- CAD shall define the base, inner gimbal, outer gimbal, mock nozzle, actuator mounts, and mechanical stops.
- The first prototype shall be easy to disassemble and modify.
- Wiring shall be strain-relieved so actuator motion does not pull on connectors.
- The test stand shall be stable on a bench without being handheld during tests.
- All tests shall start with low-speed/small-angle commands before larger profiles.

## Portfolio Requirements

The project shall produce:

- CAD screenshots and exported drawings
- Bill of materials and trade study
- Wiring diagram
- Firmware source
- Calibration procedure
- Open-loop step-response plot
- Closed-loop tracking plot
- Disturbance rejection plot
- Demo video
- Design iteration log

## Out Of Scope For Initial Build

- Live rocket motors
- Pyrotechnics
- Combustion testing
- Pressurized propellant systems
- Flight testing
- High-voltage systems

## Success Criteria

The Week 0-to-final project is successful if it demonstrates a physical test stand that:

1. Was designed in CAD.
2. Was fabricated and assembled.
3. Uses real embedded sensors and actuators.
4. Runs repeatable tests.
5. Produces plots from measured data.
6. Documents at least one design issue and iteration.

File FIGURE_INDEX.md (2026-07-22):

# Figure Index

Fast review guide for the two-axis thrust-vector-control test stand.

## 1. Two-Axis Gimbal Motion

Two-axis TVC gimbal motion

[Browser-viewable motion animation](media/tvc_gimbal_animation.html)

**What it shows:** The intended kinematics of the Rev A TVC stand: yaw rotates the outer frame, pitch rotates the inner carrier, and the nozzle/thrust vector follows the combined motion.

**Upper-division physical interpretation:** The animation distinguishes kinematics from dynamics. Kinematically, pitch and yaw are commanded rotations. Dynamically, the axes are not equivalent: yaw carries the pitch subsystem, so `I_yaw` is larger than `I_pitch`. For the same useful servo torque, yaw should have lower angular acceleration, longer settling time, and greater sensitivity to backlash, frame compliance, and servo phase lag.

## 2. Rev A CAD Baseline

Prototype 1 CAD baseline

**What it shows:** The full benchtop TVC concept: fixed base, yaw frame, pitch carrier, mock nozzle, servo envelopes, IMU location, wiring/strain-relief concept, and mechanical-stop philosophy.

**Upper-division physical interpretation:** The CAD geometry sets the plant that the controller will see. The moving mass distribution determines `I_axis`; the nozzle and pitch-servo placement create axis-dependent inertia; the center-of-mass offset and cable routing produce quasi-static disturbance moments; and printed-frame stiffness introduces compliance that can appear as additional lag, overshoot, or hysteresis in step-response data.

## 3. Rev A Printable Part Split

[Printable part manifest](cad/rev_a_part_manifest.md)

**What it shows:** The CAD has been split into individually printable parts instead of being left as a single visual model.

**Upper-division physical interpretation:** Separating the parts is not only a manufacturing step. It allows each structural member to be evaluated by load path: base plate for boundary stiffness, yaw frame for out-of-plane bending, pitch carrier for rotating inertia, servo mounts for actuator reaction loads, and hard stops for impact/limit protection. That matters because structural compliance effectively modifies `k` and `c` in the rotational plant equation.

## 4. Pitch Pre-Hardware Step Prediction

Pre-hardware pitch step prediction

**What it shows:** Predicted open-loop pitch-axis command, measured-angle proxy, tracking error, and PWM command before physical hardware data is available.

**Upper-division physical interpretation:** Pitch is expected to be the faster axis because its inertia estimate is lower. For the simplified plant,

```text
I_pitch theta_ddot + c theta_dot + k theta = tau_servo + tau_disturbance
```

lower `I_pitch` gives larger angular acceleration for the same net servo torque. The pre-hardware prediction therefore creates a falsifiable baseline: if real pitch rise time is much slower, the likely missing terms are actuator lag, bearing/gear friction, printed-frame compliance, supply-voltage sag, or underestimated moving inertia.

## 5. Yaw Pre-Hardware Step Prediction

Pre-hardware yaw step prediction

**What it shows:** Predicted yaw-axis response using the larger yaw inertia estimate.

**Upper-division physical interpretation:** Yaw carries the entire pitch subsystem, so `I_yaw` is much larger than `I_pitch`. For the same useful servo torque limit, larger inertia reduces `theta_ddot`, increases settling time, and makes yaw more sensitive to servo phase lag and structural compliance. If yaw measurements are worse than pitch, that is physically expected; the important question is whether the gap is consistent with the estimated mass properties or whether backlash/binding dominates.

## 6. Pre-Hardware Model Parameters

[Pre-hardware model parameters](data/examples/prehardware_model_parameters.json)

**What it shows:** The exact inertia, damping, stiffness, actuator lag, useful torque limit, and disturbance-torque assumptions used to generate the predicted response data.

**Upper-division physical interpretation:** Publishing model assumptions makes the project falsifiable. The first hardware logs can be used to identify whether the dominant error is in mass properties (`I_axis`), dissipative effects (`c`), restoring/compliance effects (`k`), constant bias torque, or actuator bandwidth/saturation. That is the difference between a controls demo and a measured plant-identification workflow.

## 7. Calibration And First-Test Worksheet

[Hardware calibration worksheet](docs/hardware_calibration_worksheet.md)

**What it shows:** The planned procedure for neutral calibration, IMU axis verification, first open-loop steps, pass/investigate criteria, and required photo/video evidence.

**Upper-division physical interpretation:** Calibration is treated as part of the dynamics problem. Neutral offset enters as a trim bias, wire preload enters as a constant or weakly elastic moment, backlash creates approach-direction dependence, and IMU sign/filter errors can destabilize feedback even when the controller law is correct.

## 8. Analysis Pipeline

[Test and analysis workflow](docs/test_and_analysis_workflow.md)

**What it shows:** How raw Pico serial CSV logs become response metrics and plots.

**Upper-division physical interpretation:** Metrics such as rise time, overshoot, settling time, steady-state error, and hysteresis bias are mapped to physical mechanisms instead of being treated as generic plot labels. The pipeline is designed to close the loop from CAD assumptions to measured plant behavior to Rev B design changes.

## 9. Build Readiness Package

[Build readiness checklist](docs/build_readiness_checklist.md)

**What it shows:** The project is prepared for fabrication before parts arrive: print settings, tools, electronics checks, assembly gates, and data readiness are defined.

**Upper-division physical interpretation:** Build readiness protects measurement quality. Print orientation affects stiffness and failure mode, fastener preload affects friction, voltage droop affects useful torque, and wiring preload introduces disturbance moments. Preparing these gates before assembly prevents the first test data from being corrupted by uncontrolled setup variables.

## 10. Rev A Inspection Checklist

[Rev A inspection checklist](docs/rev_a_inspection_checklist.md)

**What it shows:** The plan for measuring purchased servos, printed parts, hard-stop angles, backlash, free play, and mass properties before powered motion.

**Upper-division physical interpretation:** Inspection is a plant-identification step. Dimensional mismatch, frame warping, backlash, and mass-property errors change `I_axis`, `c`, `k`, and `tau_disturbance`; recording them gives context for prediction-versus-measurement discrepancies.

## 11. First Test Report Template

[First test report template](docs/first_test_report_template.md)

**What it shows:** The structure for turning the first hardware run into a formal engineering test report with metadata, setup evidence, raw data, plots, metrics, physical interpretation, anomalies, and Rev B actions.

**Upper-division physical interpretation:** The report template forces the correct aerospace engineering loop: assumption, prediction, measurement, discrepancy, physical cause, and design change. That is the part of the project that demonstrates hardware testing maturity rather than just assembly.

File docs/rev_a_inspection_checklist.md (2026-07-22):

# Rev A Inspection Checklist

## Objective

Verify that the printed parts, servos, and assembled mechanism match the CAD and dynamic assumptions closely enough for first powered testing.

Inspection is part of the engineering model. A dimensional error is not just a manufacturing issue; it can change inertia, friction, backlash, stiffness, hard-stop margin, or sensor alignment.

## Incoming Hardware Inspection

Complete before modifying CAD or assembling the gimbal.

| Item | CAD / expected value | Measured value | Pass / investigate | Notes |
| --- | ---: | ---: | --- | --- |
| HS-625MG length | `40.6 mm` |  |  |  |
| HS-625MG width | `19.8 mm` |  |  |  |
| HS-625MG height | `37.8 mm` |  |  |  |
| Servo mounting ear span, X | `49.5 mm` placeholder |  |  | verify on arrival |
| Servo mounting ear span, Y | `27.5 mm` placeholder |  |  | verify on arrival |
| Servo horn usable radius | TBD from horn package |  |  | affects linkage / angle scale |
| Servo spline fit | expected compatible with included horn |  |  | check slop |
| BNO085 board length | vendor nominal |  |  | affects mount |
| BNO085 board width | vendor nominal |  |  | affects mount |

Physical interpretation:

- Servo body mismatch changes mount preload and alignment. If the servo is squeezed or cocked in the mount, the output shaft can carry side load, increasing friction and hysteresis.
- Horn radius affects commanded mechanical angle per servo rotation if a linkage is used. Even for direct visual motion, horn indexing affects neutral bias.
- Spline or horn slop creates backlash. In data, this appears as approach-direction dependence and hysteresis bias.

## Printed Part Inspection

| Part | Check | Pass / investigate | Notes |
| --- | --- | --- | --- |
| base plate | lies flat on bench |  | base rocking contaminates measurements |
| base plate | mounting holes clear |  | avoid drilling that shifts alignment |
| yaw servo mount | servo fits without forcing |  | forced fit adds preload |
| yaw servo mount | slots usable |  | alignment adjustment available |
| outer yaw frame | no visible warping |  | yaw inertia/stiffness assumption preserved |
| outer yaw frame | pitch-axis supports aligned |  | prevents pitch binding |
| pitch servo mount | servo fits without forcing |  | avoids shaft side load |
| inner pitch carrier | nozzle mount aligned |  | preserves pitch balance |
| mock nozzle | printed mass acceptable |  | affects `I_pitch` and `I_yaw` |
| hard-stop blocks | stop faces intact |  | impact/load path |
| strain-relief clips | usable without wire pinch |  | reduce cable torque bias |

Physical interpretation:

- Warped or misaligned frames reduce the quality of the plant identification test. The response may show extra damping/friction or stiffness that comes from print error rather than the intended gimbal architecture.
- Printed mass affects inertia. If the nozzle or carrier mass differs significantly from estimate, update the pre-hardware model before comparing measured response.
- Hole cleanup should be recorded. Removing material or shifting holes changes alignment and may create a hidden Rev A modification.

## Assembly Inspection

| Check | Requirement | Pass / investigate | Notes |
| --- | --- | --- | --- |
| yaw axis manual sweep | free motion through `+/-10 deg` |  | no servo power |
| pitch axis manual sweep | free motion through `+/-10 deg` |  | no servo power |
| yaw hard stop angle | engages after firmware range |  | target about `+/-15 deg` |
| pitch hard stop angle | engages after firmware range |  | target about `+/-15 deg` |
| neutral nozzle alignment | near mechanical zero |  | before closed-loop test |
| wire slack | no tension through motion range |  | avoid spring torque |
| IMU alignment | visibly aligned with gimbal axes |  | sign convention |
| fastener preload | no binding after tightening |  | check before/after torque |
| base stability | no rocking or sliding |  | clamp if needed |

Physical interpretation:

- If an axis moves freely before tightening but binds after tightening, the issue is preload or alignment, not servo authority.
- If hard stops engage too close to the firmware range, transient overshoot or calibration error can cause repeated impacts. That introduces nonlinear impact dynamics and can damage servo gears.
- Wire tension creates a restoring or bias moment. In the plant model it appears as `tau_disturbance` and possibly extra `k theta`.

## Backlash And Hysteresis Hand Check

Before powered tests, gently move each axis by hand near neutral.

| Axis | Free play at nozzle tip | Approx angular free play | Pass / investigate | Notes |
| --- | ---: | ---: | --- | --- |
| pitch |  |  |  |  |
| yaw |  |  |  |  |

Use:

```text
theta_free_play ~= x_tip / L_nozzle
```

for small angles, where `x_tip` is lateral free play at the nozzle tip and `L_nozzle` is the distance from rotation axis to tip.

Physical interpretation:

- Backlash creates a dead zone where servo output changes before the nozzle angle changes. In step-response data, this increases response delay and hysteresis bias.
- Backlash is not well represented by the first linear model. If hand-measured free play is large, the first report should explicitly state that Rev A is dominated by nonlinear joint clearance.

## Mass Properties Update

Record printed masses before assembly if possible.

| Component | Estimated mass | Measured mass | Update needed? |
| --- | ---: | ---: | --- |
| inner pitch carrier |  |  |  |
| mock nozzle |  |  |  |
| pitch servo |  |  |  |
| outer yaw frame |  |  |  |
| hardware / fasteners |  |  |  |

Physical interpretation:

- Pitch inertia is driven by the pitch carrier, nozzle, IMU, and hardware about the pitch axis.
- Yaw inertia includes the entire pitch assembly plus the yaw frame. This is why yaw response is expected to be slower.
- A mass update should be reflected in `data/examples/prehardware_model_parameters.json` or documented as a known prediction error before hardware comparison.

## Inspection Outcome

| Decision | Criteria |
| --- | --- |
| proceed to servo-neutral test | all safety-critical checks pass, no binding through command range |
| proceed with caution | minor dimensional mismatch, but no hard-stop or binding issue |
| stop and rework | servo does not fit, axis binds, hard stops unsafe, wiring tension high, or IMU cannot mount rigidly |

Inspection notes should be copied into the first test report so the measured response can be interpreted in context.

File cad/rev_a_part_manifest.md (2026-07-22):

# Rev A Printable Part Manifest

This manifest defines the first separated printable parts for Prototype 1. The combined layout STL remains useful for design review, but fabrication should use separated parts so each component can be oriented, inspected, and iterated independently.

## Physical Model Used Throughout

Each axis of the gimbal is interpreted as:

```text
I_axis theta_ddot + c theta_dot + k theta = tau_servo + tau_disturbance
```

The part split is not just a CAD organization choice. It lets each physical contribution be controlled:

- `I_axis`: reduced by keeping moving parts compact and hollow where possible
- `c`: affected by shaft support, rubbing surfaces, bearing/bushing fit, and servo gear friction
- `k`: affected by printed-frame stiffness, cable routing, and gravity coupling
- `tau_disturbance`: introduced by wire preload, misalignment, fastener preload, and bench motion

## Part List

| Part file | Function | Recommended print orientation | Physical rationale |
| --- | --- | --- | --- |
| `parts/base_plate.scad` | Rigid bench reference and clamp/fastener platform | flat on bed | The base should not flex or rock, because base motion appears as false gimbal motion in IMU data. |
| `parts/yaw_servo_mount.scad` | Holds the base-mounted yaw servo | flat with slots in XY plane | Slotted holes reduce alignment-induced side load, which reduces artificial friction and hysteresis. |
| `parts/outer_yaw_frame.scad` | Carries pitch axis and moving subsystem | back face on bed if possible | Frame stiffness affects `k`; flex can produce slow settling that looks like poor controller tuning. |
| `parts/pitch_servo_mount.scad` | Holds pitch actuator relative to outer frame | flat with attachment ears down | The pitch servo mount controls input-axis alignment and should not preload the pitch shaft. |
| `parts/inner_pitch_carrier.scad` | Carries mock nozzle and IMU | orient for strong shaft features | This is moving mass; compact geometry reduces `I_pitch` and improves transient response. |
| `parts/mock_nozzle.scad` | Visible nozzle surrogate and inertial load | vertical for circularity or horizontal for quick fit check | Hollowed geometry reduces pitch inertia while preserving visual scale for video. |
| `parts/hard_stop_block.scad` | Mechanical overtravel protection | flat on bed | Stops protect against calibration/software faults and keep motion within the test envelope. |
| `parts/wire_strain_relief_clip.scad` | Captures moving wires near rotation axes | flat on bed | Reduces wire stiffness acting as an unmodeled torsion spring. |

## Why Individual STLs Matter

A single combined STL is useful for visual review, but it is not a proper manufacturing package. Printing parts separately allows:

- different print orientations for strength
- local infill/wall changes near screw holes
- easier replacement after a failure
- part-by-part fit checks against real servos and fasteners
- cleaner revision history when one weak part changes

This is also better engineering evidence. A recruiter can see that the design is being treated as hardware with tolerances, load paths, and test consequences rather than as a decorative 3D model.

## Initial Export Targets

Future exported Rev A STLs should go in:

```text
cad/exports/rev_a_parts/
```

Recommended names:

```text
base_plate.stl
yaw_servo_mount.stl
outer_yaw_frame.stl
pitch_servo_mount.stl
inner_pitch_carrier.stl
mock_nozzle.stl
hard_stop_block.stl
wire_strain_relief_clip.stl
```

## Fit-Check Sequence

Before printing the full assembly:

1. Print `yaw_servo_mount.scad` as a small fit check.
2. Verify HS-625MG body, screw clearance, and slot alignment.
3. Print `pitch_servo_mount.scad` and check attachment concept.
4. Print `inner_pitch_carrier.scad` and mock nozzle to verify moving-mass envelope.
5. Assemble without power and sweep by hand through `+/-10 deg`.
6. Verify hard stops engage near `+/-15 deg`.
7. Route wires through strain-relief clips and repeat the manual sweep.

## What To Measure After Printing

| Measurement | Why it matters |
| --- | --- |
| pitch carrier + nozzle mass | Updates `I_pitch` and gravity moment. |
| yaw frame + pitch subsystem mass | Updates `I_yaw` and servo torque margin. |
| center-of-mass offset from each axis | Predicts steady gravity bias torque. |
| free-play at nozzle tip | Estimates backlash/compliance before closed-loop tests. |
| manual return-to-neutral repeatability | Identifies friction and cable preload. |
| hard-stop angle | Confirms mechanical protection outside firmware limit. |

These measurements close the loop between CAD assumptions and physical hardware behavior.

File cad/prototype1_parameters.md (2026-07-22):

# Prototype 1 CAD Parameters

Current baseline date: `2026-07-21`

This file records the dimensional assumptions used for the first CAD layout. Vendor values are used to start the model, but all critical dimensions must be measured with calipers after parts arrive.

## Coordinate Frames

The CAD model uses a right-handed bench frame:

```text
+x = pitch-axis reference direction
+y = yaw-axis reference direction
+z = vertical/up
```

The gimbal is treated as a nested two-axis mechanism:

```text
fixed base -> yaw frame -> pitch/nozzle carrier -> mock nozzle and IMU
```

## Servo Baseline

Selected actuator: Hitec HS-625MG standard metal-gear PWM servo.

| Parameter | CAD baseline | Source / note |
| --- | ---: | --- |
| Body length | `40.6 mm` | Hitec published dimension |
| Body width | `19.8 mm` | Hitec published dimension |
| Body height | `37.8 mm` | Hitec published dimension |
| Mass | `55.2 g` | Hitec published weight |
| Spline | `24T`, about `6 mm` class | Hitec/ServoCity published spline family |
| Wire length | `300 mm` | ServoCity published value |
| Stall torque at `6.0 V` | `6.8 kg-cm` | Hitec/ServoCity published value |
| No-load speed at `6.0 V` | `0.15 s/60 deg` | Hitec/ServoCity published value |
| Deadband | `8 us` | ServoCity published value |

## Rev A Mounting Assumptions

The OpenSCAD baseline includes slotted servo mounting holes rather than fixed exact holes. This is intentional: standard-size servo mounting patterns vary slightly, and printed parts will have tolerance error.

| Parameter | Rev A placeholder | Note |
| --- | ---: | --- |
| mount slot length | `9.0 mm` | Allows alignment adjustment after printing. |
| mount slot width | `3.4 mm` | Intended for M3-class clearance; verify screw choice. |
| nominal long-axis hole span | `49.5 mm` | Standard-servo placeholder; verify on HS-625MG body. |
| nominal cross-axis hole span | `27.5 mm` | Standard-servo placeholder; verify on HS-625MG body. |
| supported shaft diameter | `4.0 mm` | Placeholder for small shaft/bushing concept. |
| bearing/bushing envelope | `8.0 mm` | Placeholder until hardware choice is finalized. |

The slotted mount design reduces alignment-induced friction. If the servo is forced into a misaligned printed mount, the output shaft can see side load, which increases hysteresis and makes step-response data harder to interpret.

## First Layout Assumptions

| Quantity | Value | Reason |
| --- | ---: | --- |
| Firmware command limit | `+/-10 deg` | Keeps motion away from hard stops during tests. |
| Mechanical hard stop | about `+/-15 deg` | Protects servo/linkage from overtravel. |
| Base plate | `160 x 120 x 6 mm` | Large enough for two standard servos and clamps. |
| Outer yaw frame width | `95 mm` | Leaves clearance around inner pitch carrier. |
| Outer yaw frame height | `95 mm` | Gives visual and wiring clearance. |
| Inner pitch carrier width | `55 mm` | Holds mock nozzle and IMU platform. |
| Mock nozzle length | `85 mm` | Large enough to see motion in video. |
| Mock nozzle diameter | `24 mm` | Lightweight printable surrogate. |
| IMU pad | `28 x 22 mm` | Fits common BNO085 breakout footprint envelope. |
| Minimum moving-wire slack | `40 mm` | Reduces cable-induced restoring moment. |

## Rev A Mass-Property Estimates

Detailed assumptions are documented in [rev_a_mass_inertia_estimate.md](rev_a_mass_inertia_estimate.md).

| Axis | Moving mass estimate | Inertia estimate | Gravity moment estimate |
| --- | ---: | ---: | ---: |
| pitch | `73 g` | `3.0e-5 kg m^2` | `0.018 N m` |
| yaw | `200 g` | `3.0e-4 kg m^2` | `0.039 N m` |

These estimates suggest the prototype is not static-torque limited. The more important Rev A risk is dynamic behavior: servo speed, deadband, gear backlash, frame compliance, and cable-induced bias.

## Physics Inputs For CAD

The CAD layout must support the actuator sizing model:

```text
tau_gravity = m g r
I_axis theta_ddot + c theta_dot + k theta ~= tau_servo + tau_disturbance
```

Key design implications:

- Keep the moving center of mass close to both rotation axes to reduce gravity bias.
- Avoid routing wires so they behave like torsion springs.
- Keep the IMU on the moving nozzle carrier, not the fixed base.
- Keep hard stops independent of the servo internal mechanical limits.
- Make the servo mounts adjustable enough to correct alignment after printing.

## Dimensions To Verify After Parts Arrive

- servo body length, width, height
- output spline diameter and horn thickness
- horn screw diameter and thread
- servo mounting-ear hole spacing
- servo wire exit location
- BNO085 board size and hole pattern
- actual printed nozzle/carrier mass and center of mass

The first CAD revision should be updated after these measurements before any final print is treated as a test article.

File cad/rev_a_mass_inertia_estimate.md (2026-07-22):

# Rev A Mass, Center-Of-Mass, And Inertia Estimate

Current estimate date: `2026-07-21`

This document estimates the moving mass properties of Prototype 1 before hardware arrives. These values are first-pass engineering estimates, not final measured properties. After printing and assembly, the moving masses and center-of-mass offsets should be measured and this file should be updated.

## Why This Matters

The gimbal is a rotational dynamics problem. For each axis, the small-angle plant can be approximated as:

```text
I_axis theta_ddot + c theta_dot + k theta = tau_servo + tau_disturbance
```

The CAD model directly sets the dominant mass-property terms:

- `I_axis`: rotational inertia of the moving gimbal/nozzle assembly
- `k`: effective stiffness from gravity coupling, printed-frame flex, and wire preload
- `tau_disturbance`: friction, cable drag, shaft misalignment, and off-axis weight

This is why CAD cannot be treated as just packaging. If the moving center of mass is far from the rotation axis, gravity creates a steady bias moment. If the mass is spread far from the axis, the same servo torque produces lower angular acceleration. If wires are routed tightly across the moving frame, they act like torsion springs and contaminate the controller response.

## Rev A Mass Budget

### Pitch Axis Moving Assembly

The pitch axis controls the inner carrier, mock nozzle, IMU board, local fasteners, horn/interface hardware, and moving wire segment.

| Component | Estimated mass |
| --- | ---: |
| printed inner pitch carrier | `30 g` |
| printed mock nozzle | `25 g` |
| BNO085 breakout | `5 g` |
| servo horn/interface hardware | `8 g` |
| moving wire slack | `5 g` |
| **pitch moving mass estimate** | **`73 g`** |

The previous actuator sizing used a deliberately conservative `0.20 kg` moving mass. The Rev A pitch estimate is lower, but the conservative sizing is still useful because it covers under-estimated print mass, extra hardware, and friction.

### Yaw Axis Moving Assembly

The yaw axis moves the pitch carrier/nozzle assembly plus the pitch servo, part of the outer frame, and wiring.

| Component | Estimated mass |
| --- | ---: |
| pitch moving assembly | `73 g` |
| pitch servo | `55 g` |
| printed outer yaw frame contribution | `45 g` |
| bearings/shafts/fasteners | `20 g` |
| moving wire slack | `7 g` |
| **yaw moving mass estimate** | **`200 g`** |

The yaw axis is expected to have larger inertia than pitch because it carries the pitch actuator and outer-frame hardware.

## Center-Of-Mass Offset Estimate

The static gravity moment is:

```text
tau_g = m g r
```

where `r` is the perpendicular offset between the rotation axis and the moving center of mass.

### Pitch Axis Gravity Bias

Using:

```text
m_pitch = 0.073 kg
r_pitch = 0.025 m
g = 9.81 m/s^2
```

gives:

```text
tau_g,pitch = 0.073 * 9.81 * 0.025
             = 0.0179 N m
             ~= 0.18 kg-cm
```

### Yaw Axis Gravity Bias

Using:

```text
m_yaw = 0.200 kg
r_yaw = 0.020 m
g = 9.81 m/s^2
```

gives:

```text
tau_g,yaw = 0.200 * 9.81 * 0.020
           = 0.0392 N m
           ~= 0.40 kg-cm
```

The HS-625MG servo is rated around `6.8 kg-cm` stall torque at `6.0 V`, so the static gravity torque estimate is far below stall torque. That does not mean the actuator is automatically adequate for closed-loop control. It only means the first CAD is not obviously torque-starved in static holding.

## Inertia Estimate

The inertial requirement is more important for transient control than the static gravity moment.

### Pitch Axis

Approximate the nozzle as a slender body with length `L = 0.085 m`, radius `r = 0.012 m`, and mass `m = 0.025 kg`. The transverse inertia estimate is:

```text
I_nozzle ~= (1/12) m (3 r^2 + L^2)
```

```text
I_nozzle ~= (1/12)(0.025)(3*0.012^2 + 0.085^2)
         ~= 1.6e-5 kg m^2
```

Adding the carrier, IMU, horn, fasteners, and wire slack gives a first-pass pitch-axis estimate:

```text
I_pitch ~= 3.0e-5 kg m^2
```

### Yaw Axis

The yaw axis carries more distributed mass. A coarse parallel-axis estimate is:

```text
I_yaw ~= sum(m_i r_i^2)
```

Using a representative radius of `0.040 m` for `0.150 kg` of moving mass plus local frame/shaft inertia:

```text
I_yaw ~= 0.150 * 0.040^2 + local terms
      ~= 2.4e-4 kg m^2 + local terms
```

Rev A working value:

```text
I_yaw ~= 3.0e-4 kg m^2
```

## Control-Relevant Interpretation

Servo stall torque at `6.0 V`:

```text
tau_stall ~= 6.8 kg-cm ~= 0.667 N m
```

A responsible design should not assume full stall torque is available for clean control. If only `20%` of stall torque is treated as useful transient control authority:

```text
tau_useful ~= 0.13 N m
```

Then the rough angular acceleration capability is:

```text
alpha_pitch ~= tau_useful / I_pitch
            ~= 0.13 / 3.0e-5
            ~= 4.3e3 rad/s^2
```

```text
alpha_yaw ~= tau_useful / I_yaw
          ~= 0.13 / 3.0e-4
          ~= 4.3e2 rad/s^2
```

These acceleration estimates are intentionally rough. They show that Rev A is likely limited by servo internal speed, deadband, backlash, and structural compliance rather than pure torque. That matches the expected hardware-test story: the first meaningful plots should focus on step-response lag, overshoot, steady-state error, hysteresis, and repeatability.

## CAD Implications

The Rev A CAD should preserve the following choices:

- keep the pitch carrier compact to reduce `I_pitch`
- avoid mounting unnecessary hardware on the pitch carrier
- mount the pitch servo so the yaw axis can carry it without excessive offset
- route IMU and servo wires with slack near the rotation axis
- use slotted servo mounts to reduce alignment-induced binding
- use mechanical hard stops outside the firmware command range

## Measurements Needed After Assembly

After parts arrive and the first print is assembled:

1. Weigh the pitch moving assembly.
2. Weigh the yaw moving assembly.
3. Balance each moving assembly to estimate center-of-mass offset.
4. Record actual servo horn geometry and linkage/direct-drive offset.
5. Repeat the gravity-torque estimate with measured values.
6. Use step-response data to infer whether the dominant limitation is inertia, servo lag, backlash, or compliance.

The portfolio value is in closing this loop: CAD estimate, physical build, measured data, and design iteration.

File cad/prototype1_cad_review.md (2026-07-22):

# Prototype 1 CAD Review Notes

## Design Intent

Prototype 1 is a benchtop two-axis TVC mechanism for controls testing. It is not a flight-weight thrust-vector mount. The CAD should make the plant easy to instrument, inspect, modify, and explain.

Primary objectives:

1. Hold a mock nozzle on two controlled axes.
2. Keep the moving center of mass close to the gimbal axes.
3. Provide hard stops outside the firmware command range.
4. Mount the IMU on the controlled moving body.
5. Route wires so they do not dominate the measured restoring torque.
6. Keep the assembly printable and repairable.

## Baseline CAD Files

| File | Purpose |
| --- | --- |
| `prototype1_parameters.md` | Dimensional assumptions and physical rationale. |
| `prototype1_gimbal_baseline.scad` | Parametric first-pass concept model. |
| `exports/prototype1_cad_baseline.svg` | Static layout preview for README/review. |

## Mechanical Architecture

The first concept uses:

- fixed base plate
- yaw servo mounted to the base
- outer yaw frame
- pitch servo mounted near the outer frame
- inner pitch/nozzle carrier
- mock nozzle
- IMU pad on the moving carrier
- visual references for `+/-15 deg` hard stops

The model intentionally separates the firmware command limit from the mechanical limit:

```text
firmware limit: +/-10 deg
mechanical stop: about +/-15 deg
```

This gives enough room for calibration error without allowing the servo or linkage to hit its internal mechanical limit during normal tests.

## Upper-Division Physical Rationale

A TVC test stand is a coupled electromechanical plant, not just a rotating bracket. In small-angle form, each axis can be interpreted as:

```text
I_axis theta_ddot + c theta_dot + k theta = tau_servo + tau_disturbance
```

The CAD directly affects every term:

| Term | CAD driver | Design implication |
| --- | --- | --- |
| `I_axis` | moving nozzle/carrier/servo mass distribution | keep mass near the rotation axes where practical |
| `c` | bearing friction, servo internal damping, rubbing surfaces | avoid printed-on-printed rubbing as the primary bearing if it causes hysteresis |
| `k` | printed-frame flex, cable stiffness, gravity coupling | strain-relieve wires and keep the CM close to the axes |
| `tau_servo` | horn geometry, spline alignment, servo voltage | use traceable servo specs and avoid binding |
| `tau_disturbance` | cable preload, misalignment, bench vibration | make disturbances visible and repeatable during tests |

The CAD baseline should therefore be evaluated by how well it supports clean system identification. The first open-loop step tests should reveal whether the dominant error source is actuator lag, backlash, structural flex, sensor filtering, or wire-induced bias.

## Design Review Checklist

Before printing Rev A:

- [ ] Confirm HS-625MG body dimensions with calipers.
- [ ] Confirm mounting-ear hole spacing.
- [ ] Confirm horn thickness, spline fit, and screw size.
- [ ] Confirm BNO085 board hole spacing and connector clearance.
- [ ] Estimate moving mass and center of mass from CAD.
- [ ] Check `+/-10 deg` motion clearance without wire strain.
- [ ] Check hard stops engage before servo/linkage binding.
- [ ] Confirm the base can be clamped or weighted during tests.
- [ ] Add labels/arrows for pitch, yaw, and IMU axes.

## Rev A Manufacturing Notes

- Use PLA+ for speed if PETG is unavailable; use PETG if extra toughness is needed.
- Print servo mounts with enough wall thickness around screw holes.
- Prefer heat-set inserts for parts expected to be removed repeatedly.
- Use fillets around frame corners to reduce stress concentration and print cracking.
- Avoid support-heavy geometry in the first revision.
- Keep fasteners accessible without disassembling the full gimbal.

## Expected First-Revision Failure Modes

These are acceptable if they are measured and used to iterate:

- servo backlash produces different measured neutral positions depending on approach direction
- printed frame flex causes slow settling or overshoot
- wire drag creates a steady-state bias torque
- IMU vibration corrupts rate measurements during fast servo steps
- servo power sag causes intermittent jitter or telemetry resets

The first CAD is successful if it produces a testable mechanism and exposes these effects clearly enough to improve Rev B.

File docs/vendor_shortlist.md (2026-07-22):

# Vendor Shortlist And Purchase Decision

Current check date: `2026-07-21`

This document converts the Prototype 1 architecture into a buyable parts list. Prices and availability should be checked again immediately before ordering.

## Selected First Purchase

Prototype 1 will use the traceable-servo path. The strict-budget servo path is retained below only as a rejected lower-cost alternative.

| Subsystem | Recommended part | Qty | Current reference price | Link | Engineering reason |
| --- | --- | ---: | ---: | --- | --- |
| Microcontroller | Raspberry Pi Pico H, pre-soldered headers | 1 | `$5.00` | <https://www.adafruit.com/product/5525> | RP2040 has enough PWM, I2C, timing, and USB serial bandwidth for a `50-100 Hz` TVC test stand controller. Headers reduce bring-up time. |
| IMU | Adafruit BNO085 9-DOF orientation breakout | 1 | `$24.95` | <https://www.adafruit.com/product/4754> | Provides quaternion/rotation-vector output for rapid first closed-loop tests while still allowing raw gyro/accel logging where available. |
| I2C cable | STEMMA QT / Qwiic JST SH cable, `100-200 mm` | 1 | about `$0.95-1.25` | <https://www.adafruit.com/product/4399> | Reduces wiring errors on the IMU interface and keeps the sensor harness clean. |
| Servo power | Regulated `5 V`, `4 A` supply | 1 | `$14.95` | <https://www.adafruit.com/product/1466> | Two servos can draw large transient current. A separate supply protects the microcontroller and telemetry from brownouts. |
| Power adapter | Female `2.1 mm` jack to screw terminal | 1 | `$2.00` | <https://www.adafruit.com/product/368> | Provides a clean way to distribute servo power without cutting the wall supply cable. |

## Servo Decision

The servo choice is the main cost/quality trade. The selected decision is Path A: two Hitec HS-625MG standard metal-gear servos.

### Path A: Traceable Servo, Stronger Documentation

| Part | Qty | Current reference price | Link | Key specs |
| --- | ---: | ---: | --- | --- |
| ServoCity Hitec HS-625MG standard metal-gear servo | 2 | `$43.99` each | <https://www.servocity.com/hs-625mg-servo/> | `5.5 kg-cm` at `4.8 V`, `6.8 kg-cm` at `6.0 V`, about `0.15 s/60 deg` at `6.0 V`, standard-size package |

This is the selected path. The benefit is that torque, speed, deadband, current, spline, mass, and dimensions are published by the vendor, which makes the CAD model and test-plan assumptions easier to defend.

Estimated electronics/servo subtotal:

```text
5.00 + 24.95 + 1.25 + 14.95 + 2.00 + 2*43.99 ~= $136.13
```

After fasteners, bearings, filament, jumpers, and shipping, this likely becomes about `$165-220`.

### Rejected Alternative: Strict-Budget Servo, Lower Cost

| Part family | Qty | Typical low-cost route | Key specs to verify before buying |
| --- | ---: | --- | --- |
| MG996R/MG995-class metal-gear PWM servo pack | 2 plus spares | Amazon/eBay/robotics suppliers | `>= 5 kg-cm` stall torque at `5-6 V`, standard-size `~40 x 20 x 43 mm`, metal gears, included horns, stall current estimate |

This path is rejected for Prototype 1 because generic servo listings can have inconsistent specs, clone variation, and weaker documentation. It would lower the cost, but it would make the first CAD model and test report less defensible.

Expected strict-budget subtotal:

```text
electronics + servo pack ~= $75-120 before mechanical hardware and shipping
```

Path B remains a fallback only if the budget changes later.

## Current Decision

Prototype 1 will buy two Hitec HS-625MG servos. This is the cleaner portfolio path because the first CAD and test report can reference traceable actuator specifications instead of relying on generic marketplace claims.

The actuator is still not assumed ideal. Even with a traceable servo, the hardware campaign must measure backlash, deadband, response time, steady-state error, and repeatability.

## CAD Inputs To Capture Before Modeling

Before the first CAD assembly is finalized, record:

| Quantity | Why it matters |
| --- | --- |
| Servo body dimensions | Determines mount geometry and gimbal spacing. |
| Output spline / horn geometry | Determines direct-drive interface and angular zero reference. |
| Servo mass | Adds to moving inertia if mounted on the moving frame. |
| Wire exit location | Affects cable routing and disturbance torque. |
| IMU board dimensions and mounting holes | Determines moving-body sensor placement. |
| Mock nozzle mass and center of mass | Determines gravity moment and required servo torque. |

## Upper-Division Physical Rationale

The first hardware purchase is not only a cost decision. It determines the physical plant that the controller sees:

```text
I_axis theta_ddot + c theta_dot + k theta = tau_servo(theta_cmd, theta_dot, V_supply) + tau_disturbance
```

The servo contributes finite bandwidth, deadband, saturation, backlash, and voltage sensitivity. The printed gimbal contributes inertia, compliance, friction, and alignment error. The IMU contributes measurement noise, filter delay, and frame-alignment uncertainty. A successful first prototype is one where these effects are small enough to close the loop, but visible enough to measure and discuss.

That is why the purchase decision is documented before buying parts. The test results will later be interpreted against these assumptions instead of being treated as disconnected plots.

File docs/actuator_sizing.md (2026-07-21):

# Actuator Sizing

## Purpose

The actuator sizing goal is not to certify a flight actuator. It is to verify that the selected hobby servos have enough torque margin to move a lightweight mock nozzle/gimbal assembly during benchtop tests.

## Free-Body Model

Each servo must overcome:

```text
tau_required ~= tau_gravity + tau_inertia + tau_friction + tau_wire + margin
```

For a first-pass static estimate, gravity torque dominates if the gimbal mass center is offset from the rotation axis:

```text
tau_gravity = m g r
```

where:

- `m` is the moving mass supported by the axis
- `g` is gravitational acceleration
- `r` is the distance from rotation axis to moving center of mass

## Prototype 1 Assumptions

| Parameter | First-pass value |
| --- | ---: |
| Moving nozzle/gimbal mass | `0.10-0.20 kg` |
| CM offset from axis | `20-40 mm` |
| Max gimbal angle | `10-15 deg` |
| Desired torque margin | `>= 3x static gravity torque` |

## Static Torque Estimate

Conservative case:

```text
m = 0.20 kg
r = 0.04 m
g = 9.81 m/s^2
```

```text
tau_gravity = m g r
             = 0.20 * 9.81 * 0.04
             = 0.078 N m
```

Convert to kg-cm:

```text
1 kg-cm = 0.0981 N m
tau_gravity ~= 0.80 kg-cm
```

With `3x` margin:

```text
tau_servo,target >= 2.4 kg-cm
```

Most metal-gear hobby servos exceed this static torque level. The real questions become backlash, bandwidth, stiffness, and current draw, which must be measured.

## Dynamic Considerations

Dynamic torque is:

```text
tau_inertia = I_axis alpha
```

For a lightweight mock nozzle, this is expected to be smaller than servo capability during low-speed prototype tests. However, aggressive step commands can excite:

- servo deadband
- gear backlash
- printed-frame flex
- linkage compliance
- IMU vibration

This is why the first tests begin with small-angle, low-speed command profiles.

The gimbal should also be interpreted as a second-order rotational plant over the small-angle range:

```text
I_axis theta_ddot + c theta_dot + k theta ~= tau_servo + tau_disturbance
```

For Prototype 1, `I_axis` comes from the moving nozzle/carrier inertia, `c` is an effective damping term from bearings, gears, and servo internal control, and `k` represents any effective stiffness or restoring moment from cable loads, flexure, or gravity coupling. The exact coefficients are not known before hardware exists. The goal of the first step-response tests is to estimate the practical behavior of this plant from data: rise time, overshoot, settling time, repeatability, and steady-state bias.

This matters because closed-loop TVC performance depends on actuator authority and phase lag, not stall torque alone. A servo with a large advertised stall torque can still be a poor TVC actuator if its response is slow, if the output shaft has backlash, or if current sag causes command-dependent motion errors.

## Servo Selection Requirement

Prototype 1 servos should satisfy:

| Requirement | Target |
| --- | ---: |
| Stall torque | `>= 5 kg-cm` preferred |
| Gear type | metal gear |
| Control | standard PWM |
| Supply | `5-6 V` external |
| Quantity | 2 plus optional spare |

## Physical Interpretation

A servo can have enough static torque and still perform poorly for controls. TVC is a bandwidth and tracking problem, not only a strength problem. The important measured quantities will be:

- commanded vs measured angle
- step-response settling time
- overshoot
- deadband/backlash
- repeatability
- current-induced brownout risk

The sizing estimate only gets the prototype into a plausible torque range. The hardware tests decide whether the actuator is actually good enough.

The physical interpretation of the `>= 5 kg-cm` requirement is therefore conservative but not final. It says the actuator should not fail the first prototype for obvious static-torque reasons. The real acceptance evidence will come from measured closed-loop behavior: if the gimbal tracks a small command with low steady-state error, limited overshoot, and no servo brownout, then the actuator is adequate for the first test article. If it overshoots, hunts, chatters near neutral, or cannot reject small disturbances, those plots become the engineering justification for a higher-bandwidth actuator or a stiffer mechanical redesign.

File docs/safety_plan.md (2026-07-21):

# Safety Plan

## Safety Scope

This project begins as a benchtop controls/mechanisms test stand. It does not use live rocket motors, propellant, combustion, pyrotechnics, compressed gas, or flight hardware.

## Hard Rules

- No live motors during initial development.
- No pyrotechnics.
- No combustion testing.
- No pressurized propellant systems.
- No tests while holding the mechanism by hand.
- No actuator tests without mechanical stops installed.
- No high-current actuator supply without common ground and basic fuse/current limiting.

## Bench Safety Controls

| Hazard | Control |
| --- | --- |
| Servo pinch points | Keep fingers clear during powered tests; use low-speed commands first |
| Overtravel | Add mechanical stops and firmware angle limits |
| Brownout/reset | Use separate actuator supply and common ground |
| Loose mechanism | Clamp or weight base during tests |
| Wire snag | Strain relief and route wires away from moving axes |
| Hot regulator/servo | Start with short-duration tests and inspect temperatures |

## Test Readiness Checklist

Before every powered test:

- [ ] Mechanism is secured to the bench.
- [ ] Mechanical stops are installed.
- [ ] Actuator range limits are enabled in firmware.
- [ ] Wires cannot enter the gimbal path.
- [ ] Power supply voltage/current are appropriate.
- [ ] Emergency unplug/switch is reachable.
- [ ] Test starts from neutral position.
- [ ] Logging is enabled.

## Test Progression

1. Manual unpowered range test.
2. Low-speed actuator movement without IMU control.
3. Open-loop small-angle step commands.
4. Larger open-loop commands.
5. Single-axis closed-loop tests.
6. Two-axis closed-loop tests.
7. Disturbance rejection by small manual perturbation.

## Safety Statement For Portfolio

The test stand is intentionally scoped as a non-propulsive GNC hardware platform. All initial tests use a mock nozzle to validate sensing, actuation, controls, and data acquisition before any propulsion-related application is considered.

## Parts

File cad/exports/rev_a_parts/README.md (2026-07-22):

# Rev A Part STL Exports

Individual print-review STLs should be exported here after each part renders successfully in OpenSCAD.

This folder is intentionally separate from `prototype1_gimbal_baseline.stl` because the baseline STL is a combined layout model. The files here should be separated part exports suitable for slicer fit checks.

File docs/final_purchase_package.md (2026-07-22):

# Final Prototype 1 Purchase Package

Current check date: `2026-07-21`

This is the recommended first purchase package for Prototype 1. Prices and stock can change, so verify the cart immediately before ordering.

## Core Buy List

| Item | Qty | Current unit price | Current subtotal | Link | Why this exact item |
| --- | ---: | ---: | ---: | --- | --- |
| Raspberry Pi Pico H with pre-soldered headers | 1 | `$5.00` | `$5.00` | <https://www.adafruit.com/product/5525> | RP2040 is sufficient for `50-100 Hz` servo/IMU logging; headers reduce bring-up friction. |
| Adafruit BNO085 9-DOF orientation IMU breakout | 1 | `$24.95` | `$24.95` | <https://www.adafruit.com/product/4754> | Gives quaternion/rotation-vector telemetry for early attitude tests. |
| STEMMA QT/Qwiic JST-SH 4-pin cable, `100 mm` | 1 | `$0.95` | `$0.95` | <https://www.adafruit.com/product/4210> | Reduces I2C wiring mistakes and keeps IMU harness compact. |
| Hitec HS-625MG metal-gear PWM servo | 2 | `$43.99` | `$87.98` | <https://www.hiteccs.com/actuators/product-details/HS-625MG> | Traceable torque, speed, deadband, dimensions, mass, and 24T spline. |
| Adafruit `5 V`, `4 A` switching supply | 1 | `$14.95` | `$14.95` | <https://www.adafruit.com/product/1466> | Separate servo power prevents Pico brownout and corrupt telemetry. |
| Female `2.1 mm` DC jack to screw terminal | 1 | `$2.00` | `$2.00` | <https://www.adafruit.com/product/368> | Clean way to distribute the servo supply without cutting the power cable. |

Core subtotal:

```text
$135.83 before tax and shipping
```

## Local/Generic Hardware

These items can be bought from Amazon, McMaster, a local hardware store, or campus/makerspace stock. Exact dimensions should be finalized after the first servo fit check.

| Item | Qty | Planning cost | Notes |
| --- | ---: | ---: | --- |
| data-capable micro-USB cable | 1 | `$5-10` | Must support data, not charge-only. |
| jumper wire kit | 1 | `$6-12` | Male/female Dupont leads are useful for Pico/servo wiring. |
| small breadboard or protoboard | 1 | `$5-10` | For first wiring pass. |
| M3 screw assortment | 1 | `$8-15` | Needed for printed mounts and hard stops. |
| M3 heat-set inserts | optional | `$8-15` | Improves repeated assembly/disassembly. |
| PETG or PLA+ filament | available stock | `$0-25` | PETG preferred for toughness; PLA+ acceptable for fit checks. |
| small clamps or rubber feet | optional | `$5-10` | Keeps base from moving during tests. |
| `4 mm` shaft / small bushings or bearings | optional | `$5-20` | Depends on whether Rev A uses supported pitch shaft or direct-drive fit check. |

Estimated full first-build cost:

```text
$165-220 before tools
```

## Why This Package Is The Right First Purchase

The selected package maximizes measured engineering value per dollar. The expensive choice is the servo, not the microcontroller or IMU. That is intentional: the servo defines actuator bandwidth, backlash, deadband, torque margin, and fit geometry. A traceable HS-625MG actuator makes the CAD and test assumptions more defensible than a generic servo pack.

The test stand should be interpreted as a rotational plant:

```text
I_axis theta_ddot + c theta_dot + k theta = tau_servo + tau_disturbance
```

Each purchase affects that plant:

| Purchase | Physical effect |
| --- | --- |
| HS-625MG servos | set actuator speed, deadband, backlash, torque authority, and input lag |
| separate `5 V`, `4 A` supply | reduces voltage sag, reset risk, and command-dependent servo jitter |
| BNO085 IMU | provides measured attitude/rate so PWM input can be compared to actual motion |
| STEMMA/Qwiic cable | reduces wiring error and keeps the IMU harness repeatable |
| M3 hardware/inserts | determines mount stiffness and whether repeated assembly changes alignment |
| filament/print settings | determine frame compliance and therefore apparent damping/stiffness |

The purpose of Prototype 1 is not to prove that hobby servos are flight hardware. It is to personally design, build, test, and characterize a real electromechanical TVC plant.

## Do Not Buy Yet

Do not buy these until after the first fit checks:

- expensive bearing kits
- aluminum stock
- digital bus servos
- BLDC gimbal motors
- custom PCBs
- extra sensors beyond the BNO085

Those could become Rev B upgrades, but buying them now would blur the first-build scope.

## Pre-Arrival Work

Before parts arrive:

1. Slice the Rev A STL files in `cad/exports/rev_a_parts/`.
2. Print only the yaw servo mount as a first fit coupon.
3. Prepare MicroPython on the Pico.
4. Keep `firmware/src/main.py` in `MODE = "neutral"`.
5. Confirm the serial logger command works on the laptop.
6. Set up a folder for dated hardware logs.

## First Measurement After Parts Arrive

Before powered motion, measure:

- actual HS-625MG body dimensions
- mounting-ear hole spacing
- horn thickness and spline fit
- servo wire exit location
- printed mount slot fit
- moving pitch carrier/nozzle mass
- center-of-mass offset from pitch and yaw axes

These measurements update the CAD assumptions and the mass/inertia estimate before Rev A is treated as a real test article.

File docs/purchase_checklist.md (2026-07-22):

# Purchase Checklist

## Prototype 1 Baseline

This checklist is based on the selected low-cost Option A architecture.

Exact vendor candidates are tracked in [vendor_shortlist.md](vendor_shortlist.md). The final buy package is [final_purchase_package.md](final_purchase_package.md). Check current price and availability again immediately before ordering.

## Electronics

| Item | Qty | Status | Notes |
| --- | ---: | --- | --- |
| Raspberry Pi Pico H with headers | 1 | Final buy item | Pre-soldered headers recommended for speed |
| Adafruit BNO085-class IMU breakout | 1 | Final buy item | STEMMA/Qwiic connector useful |
| Hitec HS-625MG metal-gear PWM servos | 2 | Final buy item | Traceable torque, speed, mass, spline, and dimensions for CAD/test documentation |
| External `5 V`, `4 A` servo supply | 1 | Final buy item | Must handle stall/current spikes |
| `2.1 mm` barrel jack to screw-terminal adapter | 1 | Final buy item | Clean servo-power distribution |
| Breadboard or protoboard | 1 | TBD | For first wiring pass |
| Jumper wires | 1 set | TBD | Include male/female options |
| STEMMA QT/Qwiic I2C cable | 1 | Final buy item | Match IMU connector |
| USB cable | 1 | TBD | Data-capable cable |

## Mechanical

| Item | Qty | Status | Notes |
| --- | ---: | --- | --- |
| PLA+/PETG filament | 1 spool or available stock | TBD | PETG preferred if available |
| M3 screw assortment | 1 set | TBD | Common for printed mechanisms |
| M3 heat-set inserts | optional | TBD | Improves serviceability |
| Small bearings/shafts | TBD | TBD | Depends on CAD layout |
| Servo horns/linkages | TBD | TBD | Often included with servos |
| Rubber feet/clamps | TBD | TBD | Stabilize base on bench |

## Tools

| Tool | Needed? | Notes |
| --- | --- | --- |
| 3D printer access | yes | For first gimbal parts |
| Soldering iron | likely | Headers/connectors |
| Multimeter | yes | Power and continuity checks |
| Calipers | yes | CAD and assembly verification |
| Small screwdrivers/hex keys | yes | Assembly |
| Protractor/angle reference | useful | Independent angle check |

## Before Buying

- [x] Choose Servo Path A from `docs/vendor_shortlist.md`.
- [x] Create final buy package.
- [ ] Confirm HS-625MG dimensions, spline, horn package, wire length, and stall-current estimate.
- [ ] Confirm IMU breakout voltage and connector type.
- [ ] Confirm Pico header option.
- [ ] Confirm servo supply voltage/current rating.
- [ ] Confirm CAD envelope so servos physically fit.
- [ ] Check whether bearings/shafts are needed or if servo output shafts carry Prototype 1.

## Budget Target

Prototype 1 target budget:

```text
about $165-220 before tools, tax, and shipping
```

If the total exceeds this range, reduce scope before buying more expensive electronics. The goal is first hardware data, not final flight-like hardware.

The selected path is the Pico/BNO085 electronics stack plus two traceable Hitec HS-625MG servos. This is more expensive than the strict-budget servo pack, but it gives the project stronger CAD inputs and a cleaner actuator-specification trail.

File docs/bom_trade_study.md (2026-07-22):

# Preliminary BOM Trade Study

This began as a Week 0 trade study. Prototype 1 now uses the low-cost Option A baseline: Raspberry Pi Pico-class microcontroller, BNO085-class IMU, metal-gear PWM servos, external servo power, and a 3D printed structure. Exact vendor candidates are listed in [vendor_shortlist.md](vendor_shortlist.md). Component availability, current pricing, and datasheets should still be verified immediately before buying parts.

## Selection Philosophy

The first build should prioritize:

- fast assembly
- easy debugging
- robust data logging
- enough actuator torque for a mock nozzle
- clean wiring
- low risk

It should not optimize for minimum mass or flight packaging. This is a benchtop test article.

## Candidate Subsystems

### Microcontroller

| Option | Strength | Risk |
| --- | --- | --- |
| Teensy-class board | Fast control loop, good serial logging, many PWM options | Higher cost |
| ESP32-class board | Inexpensive, capable, wireless optional | Timing/library complexity |
| Raspberry Pi Pico-class board | Inexpensive, deterministic enough, good documentation | More manual library integration |
| Arduino-class board | Easy bring-up | May be limiting for logging/control bandwidth |

Selected Prototype 1 direction: Raspberry Pi Pico-class board. It is low cost and provides enough PWM, I2C, timing, and USB serial telemetry for the first test stand.

### IMU

| Option | Strength | Risk |
| --- | --- | --- |
| BNO085-class fused IMU | Convenient attitude output | Fusion behavior can hide raw dynamics |
| ICM-20948-class IMU | Raw gyro/accel/mag access | More calibration/filtering work |
| MPU-6050-class IMU | Cheap and common | Older sensor, noisier, fewer features |

Selected Prototype 1 direction: BNO085-class fused IMU. It reduces bring-up time and still supports a meaningful sensor/control test if raw gyro/accel channels are logged where available.

### Actuators

| Option | Strength | Risk |
| --- | --- | --- |
| Metal-gear hobby servos | Simple PWM, easy mechanical integration | Backlash, limited telemetry |
| Digital bus servos | Better control/feedback options | More protocol complexity |
| BLDC gimbal motors | Smooth motion and control depth | Much harder electronics/control project |

Selected Prototype 1 direction: metal-gear PWM servos. Their backlash, deadband, and finite bandwidth are not hidden; they become part of the measured hardware characterization.

### Mechanical Structure

| Option | Strength | Risk |
| --- | --- | --- |
| 3D-printed PLA/PETG | Fast iteration | Flex, creep, heat sensitivity |
| Laser-cut plates | Flat and stiff | Less geometry freedom |
| Aluminum brackets | Stiffer and more professional | Slower fabrication |

Selected Prototype 1 direction: 3D print the first gimbal so failures can be corrected quickly.

## First-Build Hardware Targets

| Item | Target spec |
| --- | --- |
| Actuator range | At least `+/-10 deg` achieved gimbal motion |
| Actuator torque | Enough to move mock nozzle with margin |
| IMU update rate | At least `50 Hz`, preferably `100 Hz+` |
| Logging | CSV over USB serial |
| Power | Separate regulated actuator supply |
| Structure | Rigid base, accessible fasteners, mechanical stops |

## Prototype 1 BOM Baseline

| Item | Selected part | Quantity | Reason | Source | Cost |
| --- | --- | ---: | --- | --- | ---: |
| Microcontroller | Raspberry Pi Pico H or equivalent RP2040 board | 1 | low cost, adequate timing/PWM/I2C, headers reduce bring-up time | Adafruit or equivalent | about `$5` |
| IMU | BNO085-class breakout | 1 | fast attitude bring-up with quaternion/rotation-vector output | Adafruit or equivalent | about `$25` |
| Pitch actuator | Hitec HS-625MG metal-gear PWM servo | 1 | traceable actuator specs for CAD, torque margin, and response testing | ServoCity/Hitec | `$43.99` |
| Yaw actuator | Hitec HS-625MG metal-gear PWM servo | 1 | traceable actuator specs for CAD, torque margin, and response testing | ServoCity/Hitec | `$43.99` |
| Power supply/regulator | external `5 V`, `4 A` servo supply | 1 | avoids USB/microcontroller brownout | Adafruit or equivalent | about `$15` |
| Power adapter | `2.1 mm` jack to screw terminal | 1 | clean servo-power distribution | Adafruit or equivalent | about `$2` |
| I2C cable | STEMMA QT/Qwiic cable | 1 | reduces IMU wiring errors | Adafruit or equivalent | about `$1` |
| Bearings/shafts/fasteners | TBD from CAD | TBD | depends on direct-drive vs supported shaft layout | TBD | TBD |
| Printed material | PLA+/PETG | TBD | fast iteration | local/available | TBD |

## Trade Study Takeaway

The first prototype should be simple enough to build quickly but instrumented well enough to generate real engineering plots. The goal is not a perfect TVC mechanism on revision 1; the goal is a measured design-build-test loop with clear iteration.

The selected servo path is the traceable Hitec/ServoCity option. This increases cost, but improves documentation quality because torque, speed, deadband, current, mass, and dimensions are published. A MG996R/MG995-class budget pack would minimize cost, but it would need to be treated as an unknown actuator before any closed-loop claims are made.

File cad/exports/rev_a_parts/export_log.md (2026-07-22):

# Rev A Part Export Log

Export date: `2026-07-21`

Renderer:

```text
OpenSCAD 2021.01
```

Command pattern:

```text
/Applications/OpenSCAD-2021.01.app/Contents/MacOS/OpenSCAD \
  -o cad/exports/rev_a_parts/<part>.stl \
  cad/parts/<part>.scad
```

## Exported Parts

| STL | Source `.scad` | Render result |
| --- | --- | --- |
| `base_plate.stl` | `cad/parts/base_plate.scad` | OpenSCAD render completed, simple 3D object |
| `yaw_servo_mount.stl` | `cad/parts/yaw_servo_mount.scad` | OpenSCAD render completed, simple 3D object |
| `outer_yaw_frame.stl` | `cad/parts/outer_yaw_frame.scad` | OpenSCAD render completed, simple 3D object |
| `pitch_servo_mount.stl` | `cad/parts/pitch_servo_mount.scad` | OpenSCAD render completed, simple 3D object |
| `inner_pitch_carrier.stl` | `cad/parts/inner_pitch_carrier.scad` | OpenSCAD render completed, simple 3D object |
| `mock_nozzle.stl` | `cad/parts/mock_nozzle.scad` | OpenSCAD render completed, simple 3D object |
| `hard_stop_block.stl` | `cad/parts/hard_stop_block.scad` | OpenSCAD render completed, simple 3D object |
| `wire_strain_relief_clip.stl` | `cad/parts/wire_strain_relief_clip.scad` | OpenSCAD render completed, simple 3D object |

## Engineering Interpretation

These STLs are **Rev A print-review exports**, not final released manufacturing drawings. They prove that the separated CAD part files render successfully and can be opened in a slicer for first fit checks.

The next physical validation step is not controller tuning. It is dimensional and mechanical verification:

- servo body fit inside slotted mounts
- screw and slot clearance
- shaft/bushing fit
- hard-stop angle
- wire strain relief through `+/-10 deg` motion
- moving mass and center-of-mass measurement

This preserves the design-build-test chain:

```text
CAD assumption -> printed part -> measured fit/mass/clearance -> Rev B update
```

The control model depends on those measurements because the printed geometry sets inertia, compliance, friction, and disturbance torques.

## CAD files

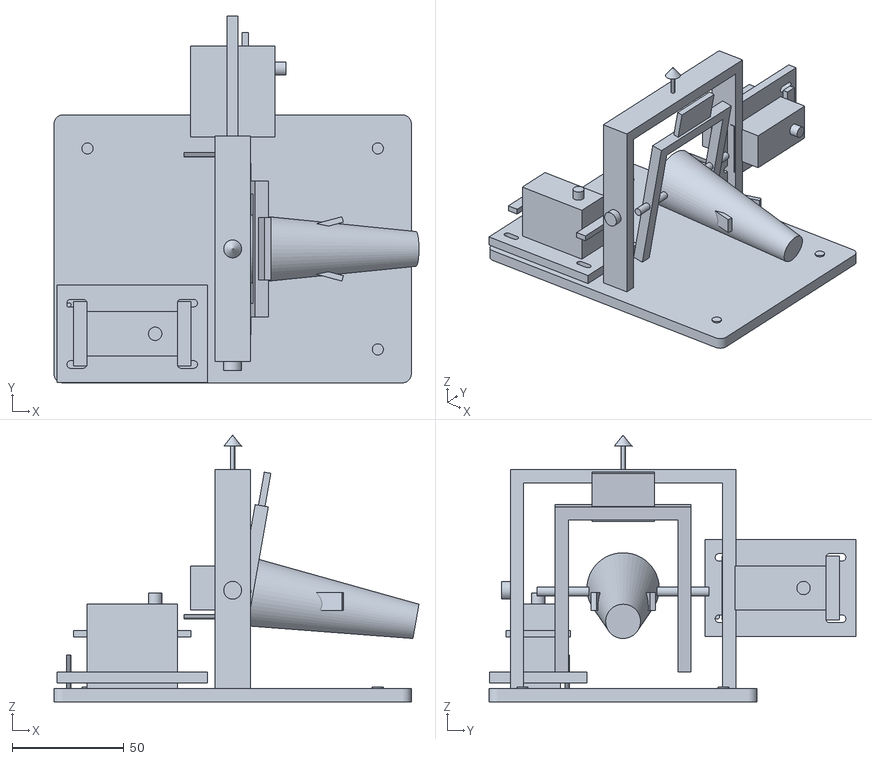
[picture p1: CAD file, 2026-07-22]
cad/exports/prototype1_gimbal_baseline.stl
163.4 x 164.2 x 119.5

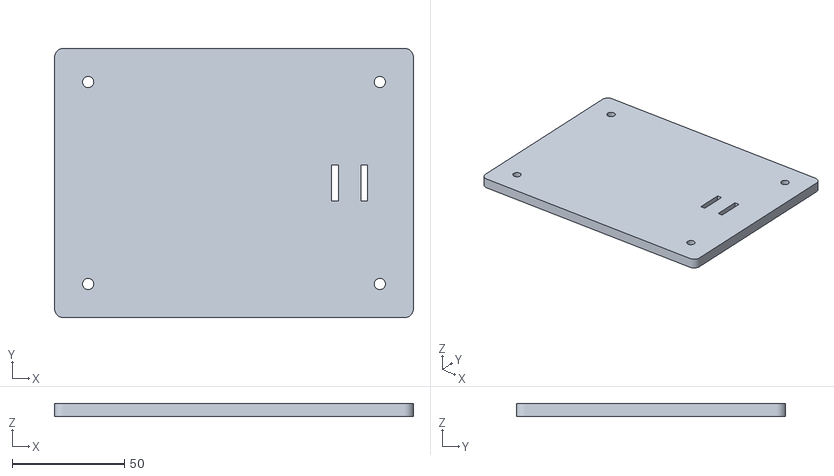
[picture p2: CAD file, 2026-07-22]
cad/exports/rev_a_parts/base_plate.stl
160.0 x 120.0 x 6.00

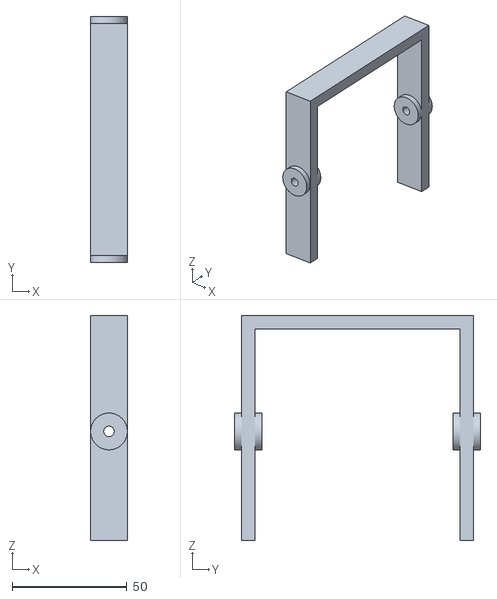
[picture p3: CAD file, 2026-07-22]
cad/exports/rev_a_parts/outer_yaw_frame.stl
16.0 x 107.0 x 98.0

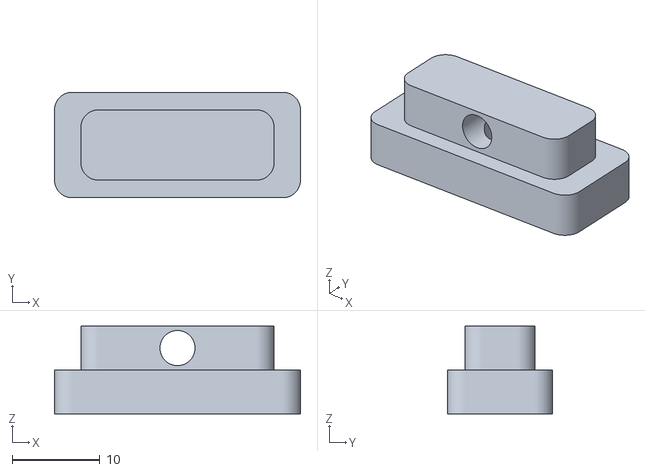
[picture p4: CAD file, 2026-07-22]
cad/exports/rev_a_parts/wire_strain_relief_clip.stl
28.0 x 12.0 x 10.0

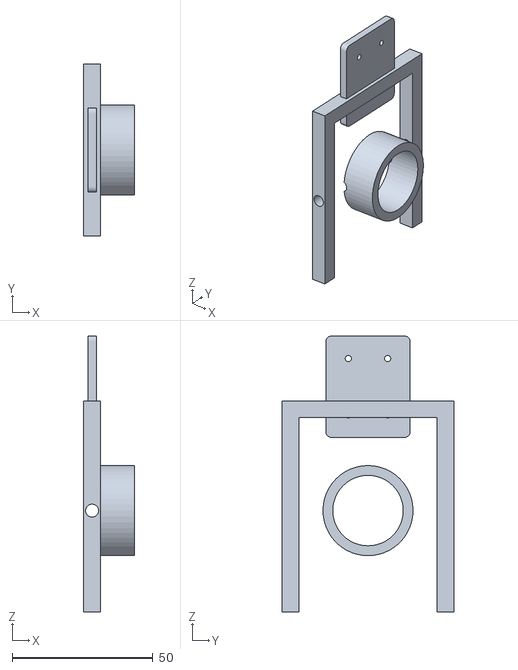
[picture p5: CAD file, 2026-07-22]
cad/exports/rev_a_parts/inner_pitch_carrier.stl
18.0 x 61.0 x 98.0

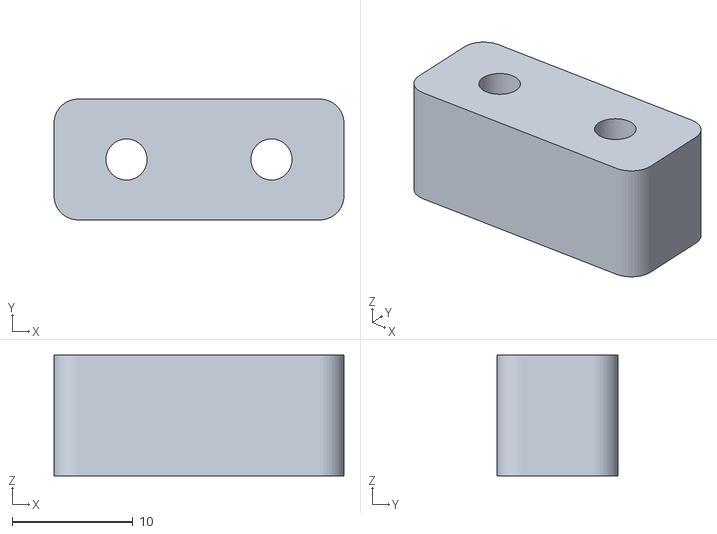
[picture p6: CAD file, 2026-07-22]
cad/exports/rev_a_parts/hard_stop_block.stl
24.0 x 10.0 x 10.0

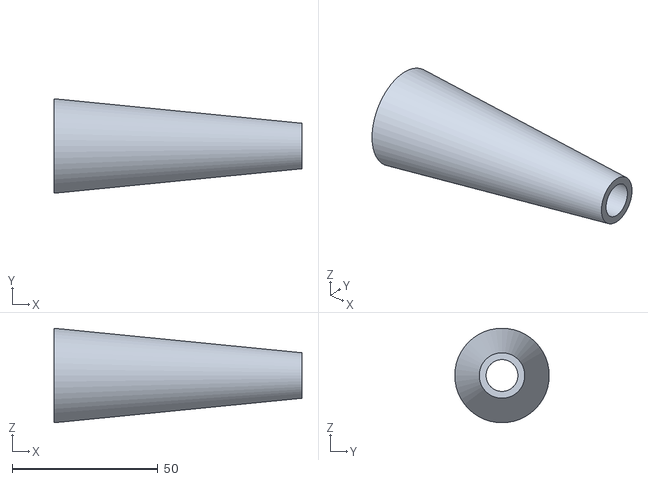
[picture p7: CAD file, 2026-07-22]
cad/exports/rev_a_parts/mock_nozzle.stl
85.0 x 32.4 x 32.4

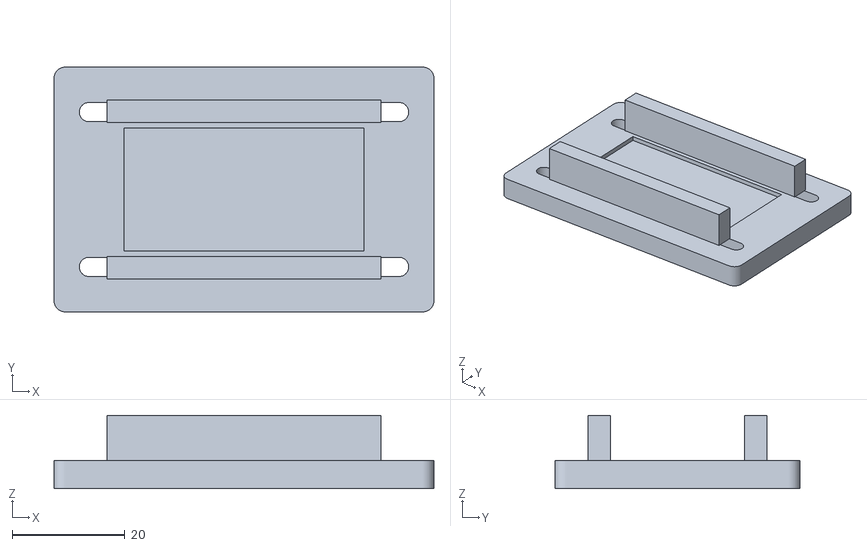
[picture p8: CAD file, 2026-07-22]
cad/exports/rev_a_parts/yaw_servo_mount.stl
67.5 x 43.5 x 13.0

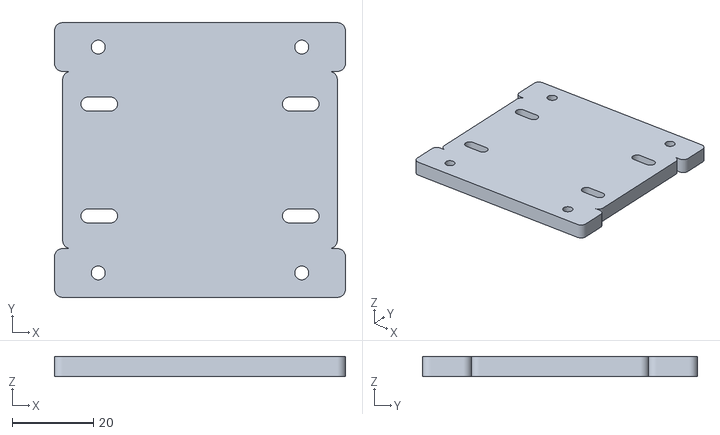
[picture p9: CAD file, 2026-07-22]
cad/exports/rev_a_parts/pitch_servo_mount.stl
71.5 x 67.5 x 5.00

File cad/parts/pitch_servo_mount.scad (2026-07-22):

include <common.scad>

// Rev A pitch servo mount.
// Print flat, then mount to the outer yaw frame.

difference() {
    union() {
        servo_mount_plate();

        // Frame attachment ears.
        translate([0, -(servo_mount_span_y/2 + 14), 0])
            rounded_plate([servo_mount_span_x + 22, 12, mount_t], 2);
        translate([0, servo_mount_span_y/2 + 14, 0])
            rounded_plate([servo_mount_span_x + 22, 12, mount_t], 2);
    }

    for (x=[-25, 25])
        for (y=[-(servo_mount_span_y/2 + 14), servo_mount_span_y/2 + 14])
            translate([x, y, 0])
                cylinder(h=mount_t + 1, d=m3_clearance_d, center=true);
}

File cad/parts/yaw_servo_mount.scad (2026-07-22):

include <common.scad>

// Rev A yaw servo mount.
// Print flat with slots in the XY plane.

difference() {
    union() {
        servo_mount_plate();

        // Alignment rail references for the HS-625MG body.
        translate([0, -(servo_w/2 + 4), mount_t/2 + 4])
            cube([servo_l + 8, 4, 8], center=true);
        translate([0, servo_w/2 + 4, mount_t/2 + 4])
            cube([servo_l + 8, 4, 8], center=true);
    }

    // Keep the servo body area open for fit tolerance.
    translate([0, 0, mount_t/2 + servo_h/2])
        servo_body_clearance(2);
}

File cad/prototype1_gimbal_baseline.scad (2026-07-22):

// Prototype 1 two-axis TVC gimbal concept.
// Units: millimeters.
// This is a parametric layout model, not a manufacturing-ready drawing.

$fn = 48;

// Servo envelope: Hitec HS-625MG vendor baseline.
servo_l = 40.6;
servo_w = 19.8;
servo_h = 37.8;
spline_d = 6.0;
spline_h = 5.0;
servo_mount_slot_l = 9.0;
servo_mount_slot_w = 3.4;
servo_mount_span_x = 49.5; // Rev A standard-servo placeholder; verify on arrival.
servo_mount_span_y = 27.5; // Rev A standard-servo placeholder; verify on arrival.

// Structural assumptions.
base_l = 160;
base_w = 120;
base_t = 6;
wall_t = 6;
mount_t = 5;
outer_w = 95;
outer_h = 95;
outer_depth = 16;
inner_w = 55;
inner_h = 72;
nozzle_l = 85;
nozzle_d = 24;
imu_l = 28;
imu_w = 22;
bearing_d = 8.0; // placeholder for small supported shaft/bushing option.
shaft_d = 4.0;

// Display angles for concept visualization.
yaw_demo_deg = 0;
pitch_demo_deg = 10;

module rounded_plate(size_xyz, r=3) {
    hull() {
        for (x=[-size_xyz[0]/2+r, size_xyz[0]/2-r])
            for (y=[-size_xyz[1]/2+r, size_xyz[1]/2-r])
                translate([x, y, 0])
                    cylinder(h=size_xyz[2], r=r, center=true);
    }
}

module servo_envelope(label_side=1) {
    color([0.15, 0.35, 0.95, 0.35])
        cube([servo_l, servo_w, servo_h], center=true);

    // Output spline reference.
    translate([servo_l/2 - 10, 0, servo_h/2 + spline_h/2])
        color([0.1, 0.1, 0.1])
            cylinder(h=spline_h, d=spline_d, center=true);

    // Mounting ears, approximate envelope only.
    for (x=[-servo_l/2 - 3, servo_l/2 + 3])
        translate([x, 0, servo_h*0.15])
            color([0.1, 0.1, 0.1, 0.35])
                cube([6, servo_w + 9, 3], center=true);

    // Wire-exit reference.
    translate([-servo_l/2 - 8, label_side*(servo_w/2 + 3), -servo_h/2 + 6])
        color([0.4, 0.4, 0.4])
            cylinder(h=18, d=2, center=true, $fn=12);
}

module slotted_hole(slot_l, slot_w, h=2) {
    hull() {
        translate([-slot_l/2 + slot_w/2, 0, 0])
            cylinder(h=h, d=slot_w, center=true);
        translate([slot_l/2 - slot_w/2, 0, 0])
            cylinder(h=h, d=slot_w, center=true);
    }
}

module servo_mount_plate() {
    difference() {
        color([0.12, 0.12, 0.12, 0.35])
            cube([servo_mount_span_x + 18, servo_mount_span_y + 16, mount_t], center=true);

        // Slotted mount holes tolerate printed error and servo-to-servo variation.
        for (x=[-servo_mount_span_x/2, servo_mount_span_x/2])
            for (y=[-servo_mount_span_y/2, servo_mount_span_y/2])
                translate([x, y, 0])
                    slotted_hole(servo_mount_slot_l, servo_mount_slot_w, mount_t + 1);
    }
}

module base_plate() {
    color([0.82, 0.82, 0.82])
        rounded_plate([base_l, base_w, base_t], 4);

    // Bench clamp/fastener references.
    for (x=[-base_l/2 + 15, base_l/2 - 15])
        for (y=[-base_w/2 + 15, base_w/2 - 15])
            translate([x, y, base_t/2 + 0.2])
                color([0.08, 0.08, 0.08])
                    cylinder(h=1.0, d=5, center=true);
}

module yaw_frame() {
    color([0.05, 0.65, 0.45, 0.75]) {
        translate([0, -outer_w/2, outer_h/2])
            cube([outer_depth, wall_t, outer_h], center=true);
        translate([0, outer_w/2, outer_h/2])
            cube([outer_depth, wall_t, outer_h], center=true);
        translate([0, 0, outer_h])
            cube([outer_depth, outer_w + wall_t, wall_t], center=true);
    }
}

module pitch_carrier() {
    color([0.85, 0.55, 0.1, 0.8]) {
        translate([0, -inner_w/2, inner_h/2])
            cube([wall_t, wall_t, inner_h], center=true);
        translate([0, inner_w/2, inner_h/2])
            cube([wall_t, wall_t, inner_h], center=true);
        translate([0, 0, inner_h])
            cube([wall_t, inner_w + wall_t, wall_t], center=true);
    }

    // IMU pad on moving carrier.
    translate([0, 0, inner_h + 7])
        color([0.3, 0.0, 0.8, 0.85])
            cube([3, imu_l, imu_w], center=true);

    // Supported pitch-axis shaft reference.
    translate([0, 0, inner_h/2])
        rotate([90, 0, 0])
            color([0.05, 0.05, 0.05])
                cylinder(h=inner_w + 22, d=shaft_d, center=true);
}

module mock_nozzle() {
    rotate([0, 90, 0])
        color([0.9, 0.15, 0.12, 0.85])
            cylinder(h=nozzle_l, d1=nozzle_d*1.35, d2=nozzle_d*0.65, center=true);
}

module hard_stop_arc(radius=42) {
    // Visual references for +/-15 deg hard-stop envelope.
    for (a=[-15, 15])
        rotate([0, 0, a])
            translate([radius, 0, 42])
                color([0.85, 0.0, 0.0])
                    cube([18, 2.5, 8], center=true);
}

module gimbal_assembly() {
    translate([0, 0, base_t/2])
        yaw_frame();

    // Bearing/bushing references for supported pitch axis.
    for (y=[-outer_w/2 - 5, outer_w/2 + 5])
        translate([0, y, base_t/2 + 8 + inner_h/2])
            rotate([90, 0, 0])
                color([0.2, 0.2, 0.2, 0.7])
                    cylinder(h=4, d=bearing_d, center=true);

    rotate([0, 0, yaw_demo_deg])
        translate([0, 0, base_t/2 + 8])
            rotate([0, pitch_demo_deg, 0]) {
                pitch_carrier();
                translate([nozzle_l/2 - 8, 0, inner_h/2])
                    mock_nozzle();
            }

    hard_stop_arc();
}

base_plate();

// Yaw servo on base.
translate([-45, -base_w/2 + 22, base_t/2 + servo_h/2])
    rotate([0, 0, 0])
        servo_envelope(1);
translate([-45, -base_w/2 + 22, base_t + 2])
    servo_mount_plate();

// Pitch servo envelope shown on right side of gimbal.
translate([0, outer_w/2 + 23, base_t/2 + 45])
    rotate([90, 0, 90])
        servo_envelope(-1);
translate([0, outer_w/2 + 23, base_t/2 + 45])
    rotate([90, 0, 90])
        servo_mount_plate();

gimbal_assembly();

// Axis references.
color([0.1, 0.1, 0.1]) {
    translate([0, 0, base_t + 100])
        cylinder(h=16, d=2, center=true);
    translate([0, 0, base_t + 108])
        cylinder(h=5, d1=8, d2=0, center=true);
}

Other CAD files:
cad/parts/base_plate.scad
cad/parts/common.scad
cad/parts/hard_stop_block.scad
cad/parts/inner_pitch_carrier.scad
cad/parts/mock_nozzle.scad
cad/parts/outer_yaw_frame.scad
cad/parts/wire_strain_relief_clip.scad

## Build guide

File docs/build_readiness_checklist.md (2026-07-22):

# Rev A Build Readiness Checklist

## Objective

Prepare the two-axis TVC test stand for fabrication, assembly, and first powered testing without relying on memory or improvisation. This checklist is completed before hardware is purchased, printed, or assembled.

The build is considered ready when the project can move through:

```text
print parts -> inspect parts -> assemble mechanism -> calibrate neutral -> collect first data
```

without needing to invent test criteria during the build.

## Print Preparation

| Item | Status | Notes |
| --- | --- | --- |
| All Rev A STL files exported |  | `cad/exports/rev_a_parts/` |
| Part manifest reviewed |  | `cad/rev_a_part_manifest.md` |
| Print material selected |  | PETG preferred; PLA+ acceptable for fit check |
| Layer height selected |  | baseline `0.20 mm` |
| Wall count selected |  | baseline `4` perimeters |
| Infill selected |  | baseline `35-50%` |
| Servo mount print orientation reviewed |  | avoid weak layer lines across servo reaction loads |
| Hard-stop print orientation reviewed |  | stop faces should not fail by layer delamination |
| Support material requirements reviewed |  | minimize supports near bearing/servo surfaces |
| Spare small parts planned |  | print extra hard stops and strain-relief clips |

Physical interpretation:

- Print orientation changes effective stiffness and failure mode. A servo mount loaded across weak layer adhesion can flex or creep, which lowers the effective plant stiffness `k` and can show up as overshoot, slow settling, or neutral drift.
- Hard stops are impact/load-limit features, so layer direction matters. A hard stop that delaminates during an overtravel event no longer protects the servo or gimbal.
- PETG is preferred for Rev A functional testing because it is less brittle and more creep/temperature tolerant than basic PLA, though PLA+ is fine for dimensional fit checks.

## Tools And Consumables

| Item | Ready? | Notes |
| --- | --- | --- |
| calipers |  | required for dimension verification |
| small screwdrivers / hex keys |  | servo hardware and printed assembly |
| drill bits or reamers |  | only for cleanup, not redesign-by-drill |
| washers/spacers |  | prevent fastener heads from crushing plastic |
| threadlocker or locknuts |  | use carefully near plastic |
| multimeter |  | servo supply verification |
| USB data cable |  | must support data, not only charging |
| camera/phone tripod |  | repeatable portfolio video evidence |
| labels/tape |  | label pitch/yaw servos and harnesses |

Physical interpretation:

- Caliper measurements are not paperwork. They close the loop between CAD assumptions and the real manufactured plant.
- Washers and spacers reduce local plastic crushing, which matters because asymmetric preload can add friction and bias torque to the gimbal.
- Voltage measurement during motion separates actuator torque problems from mechanical binding problems.

## Electronics Readiness

| Item | Status | Notes |
| --- | --- | --- |
| Pico firmware loads successfully |  | neutral mode first |
| Servo supply polarity verified |  | before connecting servo |
| Common ground plan verified |  | Pico GND and servo supply GND connected |
| Servo signal pins documented |  | pitch and yaw unambiguous |
| BNO085 wiring documented |  | I2C pins and voltage level |
| Serial logger command prepared |  | `scripts/serial_logger.py` |
| Data template prepared |  | `data/templates/hardware_step_log_template.csv` |

Physical interpretation:

- A missing common ground makes the PWM signal physically undefined at the servo input even if the code is correct.
- Supply droop reduces usable servo torque and speed. If step response is slow while voltage sags, the plant problem is electrical authority, not only mechanical inertia.
- IMU sign errors create control-law sign errors. A mathematically stable controller can become positive feedback if the measured output sign is reversed.

## Assembly Readiness

| Item | Status | Notes |
| --- | --- | --- |
| Assembly order defined |  | base -> yaw servo -> yaw frame -> pitch axis -> nozzle/IMU |
| Servo horns remain removed for first power |  | required safety gate |
| Hard stops installed before sweep |  | protect mechanism |
| Wire strain relief installed before motion |  | avoid cable torque bias |
| Manual sweep completed before power |  | confirm no binding |
| IMU mounted rigidly |  | avoid vibration-corrupted rate data |
| Base clamped or stabilized |  | prevent base motion contaminating measurement |

Physical interpretation:

- Manual sweep detects geometric binding before the servo injects torque into the mechanism.
- Wire strain relief matters dynamically because harness stiffness behaves like an unmodeled torsional spring.
- Base motion contaminates measured gimbal response. If the base moves, the IMU measurement is no longer the isolated plant output.

## Data Readiness

| Item | Status | Notes |
| --- | --- | --- |
| Calibration worksheet prepared |  | `docs/hardware_calibration_worksheet.md` |
| First-test report template prepared |  | `docs/first_test_report_template.md` |
| Raw data naming convention selected |  | `YYYYMMDD_axis_testid.csv` |
| Prediction metrics available |  | `data/examples/prehardware_*metrics.json` |
| Plot scripts verified |  | `scripts/plot_step_response.py` |
| Analysis scripts verified |  | `scripts/analyze_step_response.py` |

Recommended raw data names:

```text
data/20260721_pitch_step_2deg_a.csv
data/20260721_pitch_step_5deg_a.csv
data/20260721_yaw_step_2deg_a.csv
data/20260721_yaw_step_5deg_a.csv
data/20260721_pitch_hysteresis_5deg_a.csv
data/20260721_yaw_hysteresis_5deg_a.csv
```

Physical interpretation:

- Consistent filenames preserve the link between test condition, axis, raw data, metrics, and plots.
- The pre-hardware prediction is the baseline. The first measured response should be interpreted as an update to `I_axis`, `c`, `k`, disturbance torque, actuator lag, or actuator torque authority.

## Build Readiness Gate

Do not begin powered gimbal testing until:

- servo horns have been removed for first neutral power-on
- servo supply polarity and voltage have been verified
- common ground has been verified
- mechanical hard stops are installed
- manual sweep shows no binding through the firmware command range
- the first raw log filename and report template are prepared

This gate prevents the first hardware session from becoming an uncontrolled troubleshooting session.

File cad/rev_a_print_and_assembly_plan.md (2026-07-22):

# Rev A Print And Assembly Plan

## Purpose

Rev A is the first printable hardware configuration. Its purpose is to create a testable two-axis plant, not a final optimized mechanism. Every printed feature should either support measurement quality, protect hardware, or make the next iteration easier.

## Part Breakdown

| Part | Function | Print priority |
| --- | --- | --- |
| base plate | supports the full stand and provides clamp/fastener points | high |
| yaw servo mount | holds base-mounted yaw actuator | high |
| outer yaw frame | carries pitch axis and moving pitch subsystem | high |
| pitch servo mount | holds pitch actuator relative to outer frame | high |
| inner pitch carrier | carries mock nozzle and IMU | high |
| mock nozzle | visible moving mass for test videos and inertia estimate | medium |
| hard-stop blocks | mechanical overtravel protection | high |
| wire strain-relief clips | reduce cable-induced torque | high |

## Mechanical Choices And Physical Rationale

### Slotted Servo Mounts

Servo mounting holes are slotted in the CAD baseline.

Physical reason:

```text
misalignment -> side load / binding -> friction and hysteresis -> distorted step response
```

Slots allow the servo body to be aligned after printing. This reduces artificial friction and makes the measured actuator response more representative of the servo/gimbal system rather than printer tolerance error.

### Supported Pitch Shaft

Rev A includes a supported shaft/bearing reference for the pitch axis.

Physical reason:

```text
unsupported servo output shaft -> bending load -> gear friction/backlash growth
```

The servo should command angular position, not carry avoidable structural bending load. A supported shaft or bushing path helps separate actuation from structural support. If Rev A uses direct drive without a separate bearing, that limitation must be documented and tested.

### Hard Stops Outside Firmware Limits

Rev A uses:

```text
firmware command limit: +/-10 deg
mechanical hard stop: about +/-15 deg
```

Physical reason:

```text
calibration error or software fault -> overtravel -> servo/linkage damage
```

Hard stops should engage before the servo or linkage reaches a damaging internal limit. The gap between `10 deg` and `15 deg` provides tolerance for calibration and transient overshoot.

### IMU On Moving Carrier

The IMU is mounted on the pitch/nozzle carrier.

Physical reason:

```text
sensor on fixed base -> measures wrong state for feedback
sensor on moving body -> measures controlled output
```

This makes the feedback signal physically meaningful. The trade is that vibration and cable routing become more important, so the IMU pad should be stiff and the harness should be strain-relieved.

### Wire Slack Near Rotation Axis

Moving wires should loop near the rotation axes with slack.

Physical reason:

```text
tight wire harness -> torsional spring -> bias torque and apparent stiffness
```

If wire stiffness dominates the restoring moment, the controller will appear to be controlling the gimbal when it is partly fighting the harness. That would corrupt the actuator characterization.

## Rev A Print Settings

Initial recommendation:

| Setting | Baseline |
| --- | --- |
| Material | PETG preferred; PLA+ acceptable for first fit check |
| Layer height | `0.20 mm` |
| Perimeters/walls | `4` |
| Infill | `35-50%` |
| Top/bottom layers | `5+` |
| Servo mount region | increase walls or local modifier if available |
| Heat-set inserts | recommended for repeated assembly |

These are starting settings, not final manufacturing requirements. If the first step-response test shows structural flex or slow settling, increase stiffness before changing the controller.

## Assembly Order

1. Print base plate and servo-mount test coupons first.
2. Fit HS-625MG body into mount and verify slot alignment.
3. Install yaw servo and confirm unobstructed horn motion.
4. Assemble outer yaw frame.
5. Install pitch shaft/bushing or direct-drive interface.
6. Install pitch servo and inner carrier.
7. Mount mock nozzle and IMU pad.
8. Add wire strain relief before powered motion.
9. Manually sweep both axes through `+/-10 deg`.
10. Verify mechanical stops engage before servo/linkage binding.

## Inspection Before Power

- no servo horn contacts printed frame through `+/-10 deg`
- wires do not tighten through the motion range
- hard stops are not contacted during normal command range
- IMU board is mounted rigidly and visibly aligned
- base does not rock on the bench
- fasteners do not preload the gimbal asymmetrically

## Expected Rev A Test Consequences

The first print will likely have measurable nonidealities. The point is to capture them:

| Observation | Likely physical cause | Design response |
| --- | --- | --- |
| different neutral angle after positive vs negative approach | gear backlash or horn slop | quantify hysteresis, improve horn/interface fit |
| slow settling after command | frame flex, servo lag, or low damping | stiffen frame, reduce moving mass, retune PID |
| steady bias angle | gravity CM offset or wire preload | rebalance carrier, reroute wires |
| high-frequency IMU noise during motion | vibration or loose sensor mount | stiffen IMU pad, add filtering |
| servo jitter | power sag, signal noise, or deadband | improve power distribution, log voltage if possible |

This is the design-build-test loop the project is meant to demonstrate.

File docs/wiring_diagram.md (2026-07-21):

# Wiring Diagram

## Prototype 1 Electrical Architecture

```text
USB laptop
  |
  | USB data + microcontroller power
  v
Raspberry Pi Pico-class microcontroller
  | I2C SDA/SCL
  v
BNO085 IMU

external 5-6 V servo supply
  | +5-6 V
  | GND --------------------+
  v                         |
pitch servo                 |
yaw servo                   |
                            |
microcontroller GND --------+

microcontroller PWM pin -> pitch servo signal
microcontroller PWM pin -> yaw servo signal
```

## Critical Rule

The servo supply and microcontroller must share ground:

```text
servo_supply_GND == microcontroller_GND
```

Without common ground, PWM signals do not have a valid reference and servo behavior can become erratic.

## Power Plan

| Load | Power source |
| --- | --- |
| Microcontroller | USB from laptop |
| IMU | Microcontroller `3.3 V` |
| Servos | External regulated `5-6 V` supply |

Do not power servos from the microcontroller `5 V`/USB rail. Servo current spikes can reset the board and corrupt data logs.

## Signal Plan

| Signal | Direction | Notes |
| --- | --- | --- |
| I2C SDA | microcontroller <-> IMU | Pullups usually provided by breakout |
| I2C SCL | microcontroller <-> IMU | Keep wires short for first prototype |
| Pitch PWM | microcontroller -> pitch servo | Firmware-limited command range |
| Yaw PWM | microcontroller -> yaw servo | Firmware-limited command range |
| USB serial | microcontroller -> laptop | CSV telemetry |

## Wiring Best Practices

- Keep servo power wires thicker than signal wires.
- Twist or bundle servo power/ground where practical.
- Route IMU wires away from moving joints.
- Strain-relieve all wires on the moving gimbal.
- Label pitch and yaw servo connectors.
- Add a reachable power switch or unplug point for the servo supply.

## Bring-Up Order

1. Connect microcontroller over USB only.
2. Confirm serial output.
3. Connect IMU and confirm readings.
4. Connect one servo with external supply.
5. Confirm neutral command only.
6. Add limited sweep.
7. Add second servo.
8. Enable logging.

## Failure Modes To Watch

| Symptom | Likely cause |
| --- | --- |
| Microcontroller resets when servo moves | Servo current sag/brownout |
| Servo jitters | Bad ground reference, noisy power, weak supply |
| IMU readings jump during servo motion | Vibration, wire tug, supply noise |
| Axis moves wrong direction | Sign convention mismatch |
| Servo hits hard stop | Calibration/firmware limit error |

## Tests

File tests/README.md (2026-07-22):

# Tests

Hardware test procedures and analysis scripts will live here.

Test categories:

- mechanical range tests
- actuator calibration tests
- IMU calibration tests
- open-loop step-response tests
- closed-loop tracking tests
- disturbance rejection tests

Host-side software tests can be run with:

```bash
python3 -m unittest discover firmware/tests
python3 -m unittest discover tests
```

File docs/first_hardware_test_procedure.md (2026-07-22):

# First Hardware Test Procedure

## Objective

Safely run the first Pico/servo/telemetry test without damaging the Rev A gimbal or corrupting the data. This procedure starts with the horn removed, verifies neutral PWM, then progresses to limited motion.

Use [hardware_calibration_worksheet.md](hardware_calibration_worksheet.md) during the test and record structured data using the templates in [../data/templates/](../data/templates/).

## Required Hardware

- Raspberry Pi Pico H
- one HS-625MG servo
- external `5 V`, `4 A` servo supply
- `2.1 mm` barrel jack to screw terminal adapter
- jumper wires
- data-capable USB cable
- multimeter
- printed yaw servo mount or loose bench setup
- laptop with repo scripts

Do **not** install the servo horn for the first powered neutral test.

## Safety Logic

The firmware limit is:

```text
+/-10 deg
```

The mechanical hard-stop target is:

```text
about +/-15 deg
```

This margin exists because:

```text
unknown servo zero + installed horn + powered command = possible hard-stop impact
```

The first powered test must therefore verify neutral before the horn is attached.

## Electrical Setup

```text
laptop USB -> Pico
Pico PWM pin -> servo signal
external 5 V supply + -> servo red wire
external 5 V supply GND -> servo brown/black wire
Pico GND -> servo supply GND
```

The common ground is required because the PWM signal is measured relative to the servo ground. Without common ground, the servo input does not have a valid voltage reference.

## Step 1: Pico-Only Serial Test

1. Copy `firmware/src/*.py` onto the Pico.
2. Confirm `MODE = "neutral"` in `firmware/src/main.py`.
3. Plug Pico into USB.
4. Open serial monitor or use the logger once the port is known.

Expected telemetry:

```text
pitch_cmd_deg = 0
yaw_cmd_deg = 0
pitch_pwm_us = 1500
yaw_pwm_us = 1500
```

Pass condition:

- CSV header appears
- rows stream at about `50 Hz`
- no servo connected yet

## Step 2: Power Verification

1. Plug in the `5 V`, `4 A` supply.
2. Measure screw-terminal voltage with multimeter.
3. Confirm polarity before connecting servo.

Pass condition:

```text
servo supply ~= 5 V
polarity correct
```

## Step 3: Servo Neutral With Horn Removed

1. Connect servo power and ground.
2. Connect servo signal to the configured Pico PWM pin.
3. Ensure servo horn is removed.
4. Power Pico and servo.

Expected behavior:

- servo moves to neutral internally
- no mechanism is attached
- no brownout or USB disconnect occurs

Physical interpretation:

If the Pico resets when the servo moves, the servo supply wiring or ground reference is likely wrong. If the servo jitters, check common ground and supply stiffness before blaming the firmware.

## Step 4: Horn Installation

1. Power off servo supply.
2. Install horn as close to mechanical neutral as possible.
3. Keep the mechanism disconnected or free to move.
4. Power on in `neutral` mode again.

Pass condition:

- horn returns to expected neutral
- no hard-stop contact
- no visible servo chatter

## Step 5: Limited Sweep

Only after neutral is confirmed:

1. Change `MODE` to `sweep_pitch` or `sweep_yaw`.
2. Keep the first sweep unloaded or lightly loaded.
3. Watch for binding through the command range.
4. Log serial data:

```bash
python3 scripts/serial_logger.py --port /dev/tty.usbmodemXXXX
```

## Step 6: Analyze The First Log

```bash
python3 scripts/analyze_step_response.py data/<log>.csv --axis pitch
python3 scripts/plot_step_response.py data/<log>.csv --axis pitch
```

The first log may not include measured angle until the BNO085 driver is active. In that case, the important first result is correct command timing, PWM limits, and no power/reset faults.

## What Each Failure Means Physically

| Observation | Likely cause | Engineering response |
| --- | --- | --- |
| Pico resets when servo moves | servo current sag or missing common ground | verify external supply and ground wiring |
| servo jitters at neutral | noisy power, invalid signal reference, or deadband chatter | shorten wiring, check ground, log supply behavior |
| horn hits stop at neutral | horn installed at wrong spline index | power off, reinstall horn closer to neutral |
| motion binds near limit | CAD/mount alignment or hard-stop placement issue | adjust slotted mount or Rev A geometry |
| measured angle biased at rest | CM offset, wire preload, or horn offset | rebalance/reroute wires/calibrate neutral |
| response differs by approach direction | backlash, horn slop, friction | quantify hysteresis before PID tuning |

## Required Test Record

For the portfolio, save:

- date
- hardware revision
- firmware commit
- wiring photo
- setup photo
- raw CSV log
- generated plot
- metrics JSON
- observations and failure notes

The goal is not a perfect first test. The goal is a traceable design-build-test loop.

The first measured results should be compared directly against the pre-hardware prediction files in `data/examples/`. If the measured response disagrees with prediction, treat the disagreement as engineering information: it tells you whether the dominant missing physics is actuator lag, friction, backlash, structural compliance, wire preload, CM offset, sensor filtering, or power droop.

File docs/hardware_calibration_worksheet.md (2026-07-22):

# Hardware Calibration And First-Test Worksheet

## Objective

Create a disciplined bench-test procedure for the first powered Rev A hardware tests. The goal is to separate actuator, sensor, structure, and assembly effects before attempting closed-loop control.

The first hardware campaign answers one technical question:

```text
Does the measured gimbal response match the pre-hardware dynamic model closely enough
to justify the Rev A plant assumptions?
```

The relevant plant model is:

```text
I_axis theta_ddot + c theta_dot + k theta = tau_servo + tau_disturbance
delta_dot = (delta_cmd - delta) / tau_servo_lag
tau_servo = clamp(K_servo (delta - theta), -tau_limit, +tau_limit)
```

This worksheet exists so the first test data can be interpreted physically instead of being treated as a simple motion demo.

## Pre-Test Configuration Record

Complete this table before powering the servos with the mechanism assembled.

| Item | Value / notes |
| --- | --- |
| Test date |  |
| Operator |  |
| Printed material |  |
| Layer height / infill / wall count |  |
| Pitch servo serial/label |  |
| Yaw servo serial/label |  |
| Servo supply voltage, no load |  |
| Servo supply voltage, moving |  |
| Pico USB power source |  |
| IMU mount location |  |
| IMU axis convention confirmed | yes / no |
| Horns removed for first neutral test | yes / no |
| Mechanical hard stops installed | yes / no |
| Wiring strain relief installed | yes / no |
| Emergency power disconnect available | yes / no |

## Servo Neutral Calibration

Run servo-neutral calibration with the servo horns removed first. This avoids driving the printed mechanism into a hard stop if the PWM neutral assumption is wrong.

| Axis | Command PWM | Observed servo behavior | Accepted neutral PWM | Notes |
| --- | ---: | --- | ---: | --- |
| pitch | `1500 us` |  |  |  |
| yaw | `1500 us` |  |  |  |

After horns are installed, record the mechanical zero:

| Axis | Neutral PWM | Mechanical angle at neutral | Horn spline adjustment needed | Final zero offset |
| --- | ---: | ---: | --- | ---: |
| pitch |  |  |  |  |
| yaw |  |  |  |  |

Upper-division interpretation:

- A neutral angle offset is not just an assembly inconvenience. In the plant equation it behaves like either an actuator bias or a constant disturbance torque, depending on whether the error comes from spline indexing, center-of-mass offset, wire preload, or gravity coupling.
- If the nozzle rests off-zero while the commanded PWM is neutral, the controller will spend steady-state authority canceling a DC moment before it can reject dynamic disturbances.
- If the neutral point changes after moving positive versus negative, the mechanism has backlash or Coulomb-friction hysteresis. That violates the simple linear prediction model and must be documented before tuning gains.

## IMU Calibration And Axis Check

The BNO085 fused attitude estimate is useful only if the sensor axes are mapped correctly to the gimbal axes.

| Check | Expected result | Pass/fail | Notes |
| --- | --- | --- | --- |
| IMU detected over I2C | telemetry reports valid sensor status |  |  |
| Static zero repeatability | measured pitch/yaw remain near zero after reset |  |  |
| Positive pitch hand deflection | measured pitch sign matches convention |  |  |
| Positive yaw hand deflection | measured yaw sign matches convention |  |  |
| Rate sign check | gyro sign matches angle derivative |  |  |

Physical interpretation:

- A sign error creates positive feedback in closed-loop testing, which can drive the actuator into a stop even if the controller code is mathematically correct.
- Static attitude drift enters the measured output as a low-frequency bias. In a PID loop, integral action can mistake that sensor bias for real pointing error and command a false trim torque.
- Excessive vibration or loose IMU mounting appears as high-frequency measured rate content. That contaminates derivative feedback and can make a mechanically stable gimbal look unstable in telemetry.

## First Open-Loop Step Tests

Use small-amplitude open-loop commands first. Recommended order:

| Test ID | Axis | Command | Repeats | Purpose |
| --- | --- | --- | ---: | --- |
| `PITCH_STEP_2DEG_A` | pitch | `0 -> +2 deg -> 0` | 3 | low-risk pitch bandwidth check |
| `PITCH_STEP_5DEG_A` | pitch | `0 -> +5 deg -> 0` | 3 | compare with pre-hardware prediction |
| `YAW_STEP_2DEG_A` | yaw | `0 -> +2 deg -> 0` | 3 | low-risk yaw bandwidth check |
| `YAW_STEP_5DEG_A` | yaw | `0 -> +5 deg -> 0` | 3 | compare with pre-hardware prediction |
| `PITCH_HYST_5DEG_A` | pitch | `-5 -> +5 -> -5 deg` | 3 | backlash/friction check |
| `YAW_HYST_5DEG_A` | yaw | `-5 -> +5 -> -5 deg` | 3 | backlash/friction check |

CSV logs should use the template columns in [data/templates/hardware_step_log_template.csv](../data/templates/hardware_step_log_template.csv).

## First-Test Pass / Investigate Criteria

These are not final product requirements. They are first-build screening criteria.

| Metric | Investigate if | Physical implication |
| --- | --- | --- |
| response delay | above `0.10 s` | servo lag, command transport delay, IMU filtering, or power issue |
| rise time | more than `2x` pre-hardware prediction | higher inertia, lower servo torque, binding, or voltage sag |
| overshoot | above `20%` on small steps | low damping, compliant frame, loose horn, aggressive internal servo loop |
| settling time | above `1.0 s` | insufficient damping, geartrain slop, frame flex, or sensor filtering |
| steady-state error | above `1.0 deg` | CM bias, wire preload, horn offset, deadband, or calibration error |
| hysteresis bias | above `0.5 deg` | backlash, spline slop, bearing friction, or asymmetric cable routing |

## Comparing Hardware To Prediction

After each measured run:

```bash
python3 scripts/analyze_step_response.py data/<log>.csv --axis pitch
python3 scripts/plot_step_response.py data/<log>.csv --axis pitch
```

Then compare the measured metrics against:

- `data/examples/prehardware_pitch_step_prediction.pitch.metrics.json`
- `data/examples/prehardware_yaw_step_prediction.yaw.metrics.json`

Interpretation guide:

- Slower measured rise time means the effective angular acceleration `theta_ddot = tau_net / I_axis` is lower than predicted. That can happen because the real inertia is higher, useful servo torque is lower, friction consumes torque, or the servo supply voltage collapses under load.
- Larger measured steady-state error means the equilibrium torque balance is wrong. The real system likely has a larger constant disturbance torque, a larger elastic preload, or a servo deadband region where commanded PWM changes do not produce proportional output torque.
- More overshoot means the damping ratio is lower than predicted. In a printed mechanism, this can come from flexible side frames, compliance in the servo horn, bearing clearance, or an internal servo loop that injects phase lag near the structural mode.
- Yaw should generally be slower than pitch because the yaw servo rotates the outer frame plus the entire pitch subsystem. For the same torque limit, increasing `I_axis` reduces angular acceleration and usually increases settling time.
- If repeated tests disagree with each other, the limiting issue is probably not the linear plant. It is more likely backlash, Coulomb friction, loose fasteners, cable motion, IMU mounting, or supply noise.

## Required Photo / Video Evidence

For portfolio credibility, record:

- a still photo of the unpowered assembled test stand
- a still photo showing wiring strain relief and servo power routing
- a short video of servo-neutral testing with horns removed
- a short video of a `+/-5 deg` pitch step
- a short video of a `+/-5 deg` yaw step
- a screenshot of the corresponding plotted telemetry

The final writeup should pair each video with the measured CSV and explain the physics behind the motion.

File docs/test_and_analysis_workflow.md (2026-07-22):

# Test And Analysis Workflow

## Objective

Create a repeatable verification path from Pico telemetry to engineering plots and metrics.

```text
Pico USB serial CSV -> saved log -> analysis metrics -> plots -> physical interpretation
```

This matters because the project claim is not simply that the test stand moves. The claim is that the hardware can be designed, built, measured, and improved using evidence.

## Current Scripts

| Script | Purpose |
| --- | --- |
| `scripts/serial_logger.py` | Capture Pico USB serial CSV into `data/`. |
| `scripts/generate_synthetic_step_log.py` | Generate a synthetic step-response log before hardware is available. |
| `scripts/simulate_pre_hardware_response.py` | Predict pitch/yaw step response from Rev A inertia, damping, stiffness, disturbance torque, and actuator limits. |
| `scripts/analyze_step_response.py` | Compute step-response metrics from a CSV log. |
| `scripts/plot_step_response.py` | Generate command/response/error/PWM plots. |
| `scripts/tvc_analysis.py` | Shared analysis functions used by scripts and tests. |

## Synthetic Pipeline

Run from the repo root:

```bash
python3 scripts/generate_synthetic_step_log.py
python3 scripts/analyze_step_response.py data/examples/synthetic_pitch_step.csv --axis pitch
python3 scripts/plot_step_response.py data/examples/synthetic_pitch_step.csv --axis pitch
```

Outputs:

```text
data/examples/synthetic_pitch_step.csv
data/examples/synthetic_pitch_step.pitch.metrics.json
plots/examples/synthetic_pitch_step_pitch_step_response.svg
```

## Pre-Hardware Prediction Pipeline

Run from the repo root:

```bash
python3 scripts/simulate_pre_hardware_response.py
python3 scripts/analyze_step_response.py data/examples/prehardware_pitch_step_prediction.csv --axis pitch
python3 scripts/analyze_step_response.py data/examples/prehardware_yaw_step_prediction.csv --axis yaw
python3 scripts/plot_step_response.py data/examples/prehardware_pitch_step_prediction.csv --axis pitch
python3 scripts/plot_step_response.py data/examples/prehardware_yaw_step_prediction.csv --axis yaw
```

Outputs:

```text
data/examples/prehardware_model_parameters.json
data/examples/prehardware_pitch_step_prediction.csv
data/examples/prehardware_yaw_step_prediction.csv
data/examples/prehardware_pitch_step_prediction.pitch.metrics.json
data/examples/prehardware_yaw_step_prediction.yaw.metrics.json
plots/examples/prehardware_pitch_step_prediction_pitch_step_response.svg
plots/examples/prehardware_yaw_step_prediction_yaw_step_response.svg
```

The prediction model is intentionally simple:

```text
I_axis theta_ddot + c theta_dot + k theta = tau_servo + tau_disturbance
delta_dot = (delta_cmd - delta) / tau_servo_lag
tau_servo = clamp(K_servo (delta - theta), -tau_limit, +tau_limit)
```

The important portfolio point is that the prediction is falsifiable. If the measured hardware response disagrees with the prediction, that disagreement identifies which physical effect is under-modeled: actuator bandwidth, friction, backlash, structural compliance, wire preload, CM offset, or sensor/filter delay.

## Hardware Pipeline

After the Pico is connected:

```bash
python3 scripts/serial_logger.py --port /dev/tty.usbmodemXXXX
```

Then run:

```bash
python3 scripts/analyze_step_response.py data/<log>.csv --axis pitch
python3 scripts/plot_step_response.py data/<log>.csv --axis pitch
```

## Upper-Division Physical Interpretation

The measured response should be interpreted through the rotational plant:

```text
I_axis theta_ddot + c theta_dot + k theta = tau_servo + tau_disturbance
```

The metrics are not generic plotting quantities. Each one maps to a physical mechanism:

| Metric | Physical interpretation |
| --- | --- |
| response delay | actuator electronics, servo internal loop delay, IMU/filter delay, or command transport latency |
| rise time | combined servo speed, moving inertia, and effective control authority |
| overshoot | low damping, frame compliance, servo internal control behavior, or excessive command aggressiveness |
| settling time | damping, structural flex, bearing friction, and sensor filtering |
| steady-state error | center-of-mass gravity bias, wire preload, servo deadband, or horn offset |
| peak tracking error | worst transient pointing error during maneuver |
| hysteresis bias | gear backlash, horn slop, friction, or approach-direction dependence |

For a TVC mechanism, static torque margin alone is insufficient. A servo can hold the nozzle and still be a poor actuator if it has excessive phase lag, deadband, backlash, or voltage-sensitive response. The analysis pipeline exists to expose those effects quantitatively.

The pre-hardware prediction should be compared against the first measured log using the same metrics. That comparison is more rigorous than simply showing that the nozzle moves. A predicted rise time that is too optimistic points to unmodeled actuator lag, binding, or supply-voltage sag. A predicted steady-state error that is too small points to unmodeled constant moments from center-of-mass offset, cable preload, servo spline indexing, or deadband. A predicted overshoot that is too low points to underestimated compliance or insufficient damping. A pitch/yaw performance split is physically expected because the yaw axis carries the full pitch assembly, increasing yaw inertia and reducing angular acceleration for the same servo torque.

## What Makes A Good First Result

For Rev A, a good result is not perfect tracking. A good result is a clean dataset that identifies the dominant nonideality:

- if the response is slow, actuator bandwidth is the likely limiter
- if the final angle is biased, check CM offset and wire preload
- if the path depends on approach direction, backlash/hysteresis is likely
- if the response rings or rebounds, check structural compliance and damping
- if telemetry jumps during motion, check IMU mounting and power noise

That evidence drives Rev B CAD and firmware changes.

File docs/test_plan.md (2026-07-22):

# Test Plan

## Test Philosophy

The project should prove performance with data, not just video. Every major claim should map to a repeatable test and a plot.

## Test 1: Mechanical Range Test

Purpose: verify physical travel and stops.

Procedure:

1. Power off the system.
2. Move gimbal manually through pitch and yaw.
3. Confirm hard stops prevent overtravel.
4. Record measured range.

Pass criteria:

- Both axes move at least `+/-10 deg`.
- No binding through the expected range.
- Wires do not restrict motion.

## Test 2: Actuator Neutral Calibration

Purpose: map PWM command to approximate gimbal angle.

Detailed first-hardware procedure: [first_hardware_test_procedure.md](first_hardware_test_procedure.md)

Procedure:

1. Command neutral PWM.
2. Measure physical neutral.
3. Sweep small increments around neutral.
4. Record command vs measured angle.

Plot:

```text
actuator_command_us vs measured_angle_deg
```

Pass criteria:

- Repeatable neutral position.
- Monotonic command-to-angle response.

## Test 3: Open-Loop Step Response

Purpose: characterize actuator dynamics before closing the loop.

Procedure:

1. Command a small pitch step.
2. Log measured angle and gyro rate.
3. Repeat for yaw.
4. Repeat for larger but safe commands.

Metrics:

- rise time
- settling time
- overshoot
- steady-state error
- backlash/deadband estimate

## Test 4: Closed-Loop Single-Axis PID

Purpose: demonstrate controlled tracking on one axis.

Procedure:

1. Enable pitch-axis PID only.
2. Command small step input.
3. Tune gains conservatively.
4. Repeat for yaw axis.

Plot:

```text
commanded_angle_deg, measured_angle_deg, tracking_error_deg, actuator_output
```

Pass criteria:

- Settling time under `0.5 s` for small commands.
- Steady-state error under `1 deg`.
- No sustained oscillation.

## Test 5: Two-Axis Tracking

Purpose: demonstrate coupled operation.

Procedure:

1. Command pitch and yaw steps separately.
2. Command combined pitch/yaw profile.
3. Log cross-axis coupling.

Physical interpretation:

If a pitch command produces yaw motion, the mechanism has cross-axis coupling from geometry, flex, linkage alignment, sensor placement, or controller coupling.

## Test 6: Disturbance Rejection

Purpose: show closed-loop recovery from a small external perturbation.

Procedure:

1. Hold neutral command.
2. Apply a small manual disturbance to the mock nozzle.
3. Release.
4. Log response.

Pass criteria:

- Gimbal returns near neutral.
- Response is damped.
- No actuator saturation or mechanical binding.

## Test Report Template

Each test should produce:

- date
- hardware revision
- firmware commit
- test objective
- setup photo
- raw CSV log
- plot
- metrics
- observations
- failure/iteration notes

## Minimum Portfolio Plot Set

- open-loop actuator step response
- closed-loop command tracking
- tracking error vs time
- disturbance rejection response
- command vs measured calibration curve

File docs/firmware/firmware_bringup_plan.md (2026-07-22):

# Firmware Bring-Up Plan

## Objective

Bring up the Pico controller without risking servo or gimbal damage. The firmware sequence intentionally starts open-loop because the physical plant must be characterized before closed-loop control claims are meaningful.

## Embedded Control Chain

The first controller stack is:

```text
test mode -> commanded angle -> safety clamp -> PWM pulse width -> servo -> gimbal motion -> IMU/telemetry
```

The current firmware implements the first half of that chain:

- command profiles
- `+/-10 deg` angle clamp
- angle-to-PWM conversion
- servo neutral/sweep/step commands
- BNO085 detection placeholder
- CSV telemetry

## Why Open-Loop Comes Before PID

The rotational plant is:

```text
I_axis theta_ddot + c theta_dot + k theta = tau_servo + tau_disturbance
```

The controller cannot be tuned intelligently until the physical terms are observed:

| Physical effect | Where it appears in data |
| --- | --- |
| servo speed limit | rise time and phase lag |
| gear backlash | different output angle depending on approach direction |
| deadband | small PWM changes produce no motion |
| frame compliance | slow settling or elastic rebound |
| wire preload | steady-state bias or asymmetric response |
| sensor filtering | delayed or smoothed attitude/rate telemetry |

Open-loop step and sweep tests identify these effects before a feedback loop tries to hide them.

## Bring-Up Sequence

### 1. Pico Only

- Load MicroPython.
- Copy `firmware/src/*.py` onto the Pico.
- Keep `MODE = "neutral"`.
- Confirm USB serial prints CSV header and rows.

Expected result:

```text
pitch_cmd_deg = 0
yaw_cmd_deg = 0
pitch_pwm_us = 1500
yaw_pwm_us = 1500
```

### 2. Servo Signal Without Mechanical Load

- Connect one HS-625MG signal wire.
- Use external `5 V` servo supply.
- Confirm common ground.
- Keep servo horn removed for first powered test.

Physical reason:

```text
unknown neutral + installed horn + powered servo = possible hard-stop impact
```

### 3. Neutral And Limited Sweep

- Install horn after neutral is confirmed.
- Manually verify clearance.
- Switch to `sweep_pitch` or `sweep_yaw`.
- Watch for binding, jitter, or power sag.

The command is limited to `+/-10 deg`, which preserves margin before the `+/-15 deg` mechanical stop.

### 4. IMU Detection

- Connect BNO085 over I2C.
- Confirm `imu_present = 1`.
- Confirm quaternion fields update after the actual driver is added.

### 5. Open-Loop Data Collection

Run:

```text
sweep_pitch
sweep_yaw
step_pitch
step_yaw
```

Save serial CSV logs in:

```text
data/
```

### 6. Analysis Before PID

Use the logs to estimate:

- rise time
- overshoot
- settling time
- steady-state error
- repeatability
- hysteresis/deadband

Only after this should `closed_loop_pid` be added.

## Safety Rules

- Never power servos from Pico USB.
- Never command sweep before verifying neutral.
- Never run with loose wires near the gimbal axes.
- Keep hands clear when servo power is connected.
- Use mechanical stops outside firmware limits.

## Portfolio Interpretation

This bring-up plan demonstrates that the firmware is tied to physical reasoning. The goal is not just "make the servo move." The goal is to measure how the commanded input maps through a real actuator and flexible mechanism into motion, then use that evidence to justify controller design.

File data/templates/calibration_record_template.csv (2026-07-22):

date | test_id | axis | neutral_pwm_us | mechanical_zero_deg | positive_limit_deg | negative_limit_deg | supply_v_no_load | supply_v_moving | imu_zero_deg | gyro_bias_dps | hysteresis_bias_deg | operator_notes
YYYY-MM-DD | CAL_NEUTRAL_A | pitch | 1500 | 0.0 | 10.0 | -10.0 | 5.0 | 5.0 | 0.0 | 0.0 | 0.0 | replace example row after calibration

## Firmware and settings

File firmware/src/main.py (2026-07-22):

"""Raspberry Pi Pico Rev A bring-up firmware.

Default mode is neutral for safety. Change MODE only after confirming external
servo power, common ground, and unobstructed mechanical travel.
"""

import time

from actuators import ServoAxis
from config import LOOP_DT_S, LOOP_HZ, PITCH_SERVO_PIN, YAW_SERVO_PIN
from imu_bno085 import BNO085
from profiles import PROFILES
from telemetry import print_header, print_row

# Safe default. Valid modes: neutral, sweep_pitch, sweep_yaw, step_pitch, step_yaw.
MODE = "neutral"


def millis():
    try:
        return time.ticks_ms()
    except AttributeError:
        return int(time.time() * 1000)


def sleep_dt():
    time.sleep(LOOP_DT_S)


def run():
    pitch = ServoAxis(PITCH_SERVO_PIN, "pitch")
    yaw = ServoAxis(YAW_SERVO_PIN, "yaw")
    imu = BNO085()

    profile = PROFILES.get(MODE, PROFILES["neutral"])
    start_ms = millis()

    pitch.neutral()
    yaw.neutral()

    print("# two_axis_tvc_test_stand Rev A firmware")
    print("# loop_hz={}".format(LOOP_HZ))
    print("# mode={}".format(MODE))
    print_header()

    while True:
        now_ms = millis()
        t_s = (now_ms - start_ms) / 1000.0

        pitch_cmd, yaw_cmd = profile(t_s)
        pitch_cmd, pitch_pwm = pitch.command_deg(pitch_cmd)
        yaw_cmd, yaw_pwm = yaw.command_deg(yaw_cmd)
        imu_data = imu.read()

        row = {
            "time_ms": now_ms - start_ms,
            "mode": MODE,
            "pitch_cmd_deg": pitch_cmd,
            "yaw_cmd_deg": yaw_cmd,
            "pitch_pwm_us": pitch_pwm,
            "yaw_pwm_us": yaw_pwm,
        }
        row.update(imu_data)
        print_row(row)
        sleep_dt()


run()

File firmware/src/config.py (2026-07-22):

"""Prototype 1 firmware configuration.

Units are explicit because firmware constants become physical assumptions.
The first hardware tests should update these values after calibration.
"""

# Control-loop timing.
LOOP_HZ = 50
LOOP_DT_S = 1.0 / LOOP_HZ

# Raspberry Pi Pico GPIO assignments.
PITCH_SERVO_PIN = 14
YAW_SERVO_PIN = 15
I2C_SDA_PIN = 4
I2C_SCL_PIN = 5
I2C_FREQ_HZ = 400_000

# Servo PWM convention for hobby servos.
SERVO_PWM_HZ = 50
SERVO_MIN_US = 1000
SERVO_NEUTRAL_US = 1500
SERVO_MAX_US = 2000

# Commanded gimbal envelope.
FIRMWARE_LIMIT_DEG = 10.0
MECHANICAL_STOP_DEG = 15.0

# Initial angle-to-PWM slope.
# This is deliberately conservative: +/-10 deg maps to +/-200 us.
# Update after measuring actual horn/gimbal geometry.
US_PER_DEG = 20.0

# Test profile settings.
SWEEP_AMPLITUDE_DEG = 8.0
SWEEP_PERIOD_S = 4.0
STEP_AMPLITUDE_DEG = 5.0
STEP_PERIOD_S = 2.0

# BNO085 I2C address is commonly 0x4A or 0x4B depending on breakout setup.
BNO085_I2C_ADDR_CANDIDATES = (0x4A, 0x4B)

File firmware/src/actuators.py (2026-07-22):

"""Servo actuator mapping for the two-axis TVC stand.

The servo command is not treated as an ideal angle source. The output is a
bounded PWM request that will later be compared against measured IMU response.
"""

try:
    from machine import Pin, PWM
except ImportError:  # Allows host-side unit tests without MicroPython.
    Pin = None
    PWM = None

from config import (
    FIRMWARE_LIMIT_DEG,
    SERVO_MAX_US,
    SERVO_MIN_US,
    SERVO_NEUTRAL_US,
    SERVO_PWM_HZ,
    US_PER_DEG,
)


def clamp(value, low, high):
    return max(low, min(high, value))


def clamp_angle_deg(angle_deg):
    return clamp(float(angle_deg), -FIRMWARE_LIMIT_DEG, FIRMWARE_LIMIT_DEG)


def angle_to_pwm_us(angle_deg):
    """Map desired nozzle angle to PWM microseconds with safety clamping."""
    limited_angle = clamp_angle_deg(angle_deg)
    pwm_us = SERVO_NEUTRAL_US + US_PER_DEG * limited_angle
    return int(round(clamp(pwm_us, SERVO_MIN_US, SERVO_MAX_US)))


def pwm_us_to_duty_u16(pwm_us, pwm_hz=SERVO_PWM_HZ):
    """Convert pulse width to Pico PWM duty_u16 units."""
    period_us = 1_000_000.0 / pwm_hz
    duty_fraction = clamp(pwm_us / period_us, 0.0, 1.0)
    return int(round(duty_fraction * 65535))


class ServoAxis:
    def __init__(self, pin_id, name):
        self.name = name
        self.last_cmd_deg = 0.0
        self.last_pwm_us = SERVO_NEUTRAL_US
        self._pwm = None

        if PWM is not None:
            self._pwm = PWM(Pin(pin_id))
            self._pwm.freq(SERVO_PWM_HZ)

    def command_deg(self, angle_deg):
        self.last_cmd_deg = clamp_angle_deg(angle_deg)
        self.last_pwm_us = angle_to_pwm_us(self.last_cmd_deg)

        if self._pwm is not None:
            self._pwm.duty_u16(pwm_us_to_duty_u16(self.last_pwm_us))

        return self.last_cmd_deg, self.last_pwm_us

    def neutral(self):
        return self.command_deg(0.0)

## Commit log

2026-07-21 Lock Prototype 1 hardware baseline
2026-07-21 Add Prototype 1 vendor shortlist
2026-07-22 Select traceable servo path for Prototype 1
2026-07-22 Start Prototype 1 CAD baseline
    [prototype1_gimbal_baseline.scad]
2026-07-22 Add Rev A CAD physics refinement
    [prototype1_gimbal_baseline.scad]
2026-07-22 Add rendered CAD review STL
    [prototype1_gimbal_baseline.stl]
2026-07-22 Split Rev A CAD into printable parts
    [base_plate.scad, base_plate.stl, common.scad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]
2026-07-22 Add Pico firmware bring-up skeleton
2026-07-22 Add TVC data analysis pipeline
    [synthetic_pitch_step.csv]
2026-07-22 Add pre-hardware response simulation
    [prehardware_pitch_step_prediction.csv, prehardware_yaw_step_prediction.csv]
2026-07-22 Add hardware calibration roadmap
    [calibration_record_template.csv, hardware_step_log_template.csv]
